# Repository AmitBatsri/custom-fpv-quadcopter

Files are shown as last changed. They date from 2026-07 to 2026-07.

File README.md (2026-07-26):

# Custom FPV Quadcopter
A custom quadcopter built from scratch: STM32F405 flight controller PCB, embedded firmware, ESP-NOW wireless controller, and 3D-printed frame.
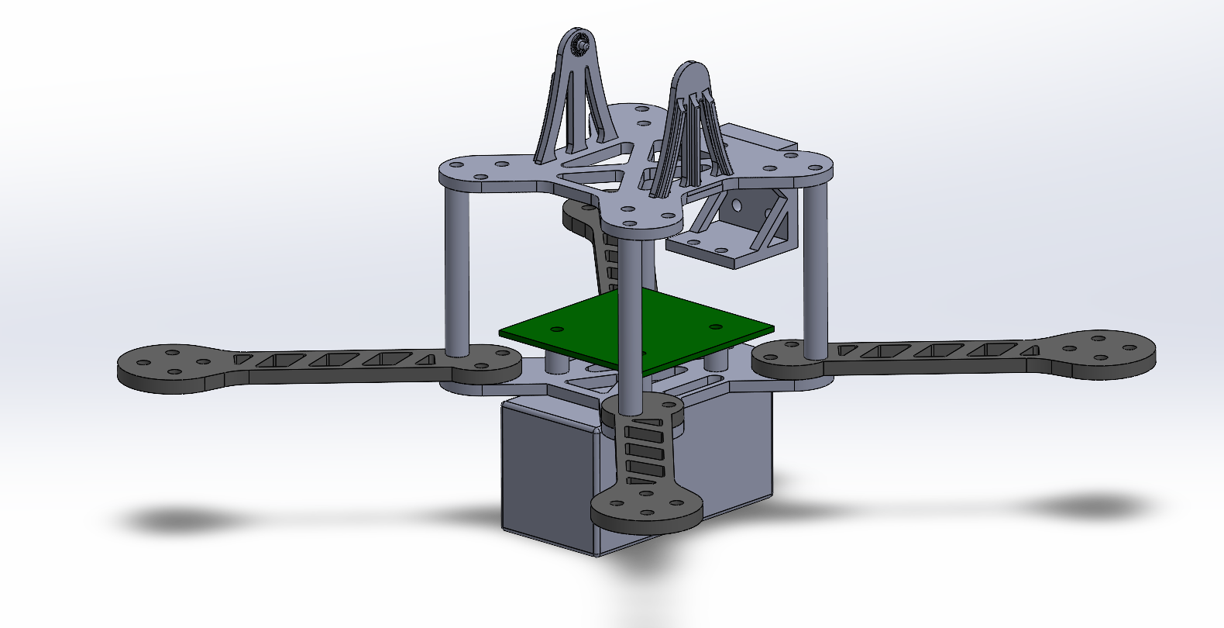
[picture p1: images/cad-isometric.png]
Full CAD assembly

## Overview

This project is a 5-inch FPV quadcopter featuring a fully custom frame, electronics package, and firmware built from individual parts using university equipment and resources. At its core is a custom 4-layer flight controller PCB built around an STM32F405 microcontroller, interfacing with an IMU and barometer over SPI, I²C, and UART. The drone communicates wirelessly through ESP-NOW with a custom handheld controller, and the goal is to achieve stable flight with live video streaming from an onboard camera.

The motivation behind the project is to gain hands-on experience in PCB design, embedded systems, and industry tools including KiCad, SolidWorks, and STM32CubeIDE. In addition, I find flight and aerial technology fascinating as they draw multiple engineering concepts to life. Rather than using an off-the-shelf flight controller, designing the project from the ground up meant working through the full engineering process, integrating mechanical design, embedded systems, and software development.

The part I'm most proud of is the flight controller PCB. Designing it from a blank schematic meant making every engineering decision myself, including component selection, power architecture, sensor integration, and layout with attention to multi-rail power distribution and noise isolation, which are all choices and considerations crucial to the performance of the drone. 

Future goals: autonomous flight capabilities and a potential payload claw mechanism.

## System Architecture

The system is split into three independent subsystems: a handheld 3D-printed controller, the drone's flight and communication electronics, and a standalone video feed. The controller and drone communicate wirelessly over ESP-NOW, while the onboard ESP32-CAM streams video directly to a browser over its own Wi-Fi connection.

```mermaid
graph TD
    subgraph Controller["Handheld Controller"]
        JS["Joysticks + Switches"]
        OLED["OLED Display"]
        S3["ESP32-S3"]
        JS --> S3
        S3 --> OLED
    end

    subgraph Drone["Drone"]
        WROOM["ESP32-WROOM<br/>(Radio Link)"]
        STM["STM32F405<br/>(Flight Controller)"]
        IMU["IMU"]
        BARO["Barometer"]
        CURR["Current Sensor"]
        ESC["4-in-1 ESC"]
        MOTORS["4 Motors"]

        WROOM -->|UART| STM
        IMU -->|SPI| STM
        BARO -->|I2C| STM
        CURR -->|I2C / ADC| STM
        STM -->|DSHOT| ESC
        ESC --> MOTORS
    end

    subgraph Video["Video Feed"]
        CAM["ESP32-CAM"]
        BROWSER["Browser"]
        CAM -->|Wi-Fi| BROWSER
    end

    S3 <-->|ESP-NOW| WROOM
```

## Hardware

### Flight Controller PCB

The flight controller is a custom 4-layer PCB (52 × 52 mm) built around an STM32F405RGT6 microcontroller. It integrates all sensing, power regulation, and motor interfacing needed to fly the quadcopter on a single compact board.

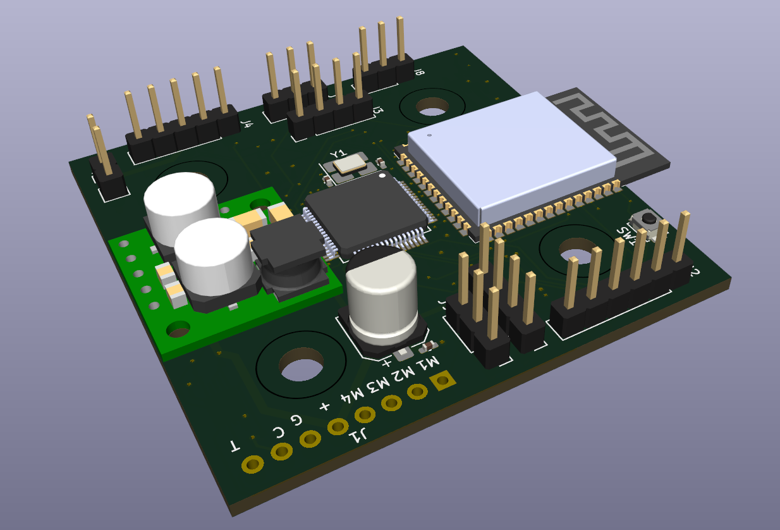
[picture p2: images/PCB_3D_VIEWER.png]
Flight controller 3D view


**Key components:**
- **MCU:** STM32F405RGT6 (168 MHz Cortex-M4F, 1 MB flash)
- **IMU:** BMI270 (SPI) — gyroscope and accelerometer for attitude sensing
- **Barometer:** BMP384 (I2C) — altitude measurement
- **Power monitor:** INA226 (I2C) — battery voltage and current sensing
- **Motor interface:** DSHOT to a 4-in-1 ESC
- **Wireless link:** UART to an onboard ESP32-WROOM

**Power architecture:** The board runs directly off a 4S LiPo, stepping the battery voltage down to a 5 V rail via a buck regulator, then to separate 3.3 V rails through linear voltage regulators consisting of a dedicated rail for the ESP32 to isolate it from the flight-related

**Design highlights:**  Multi-rail power distribution, decoupling placed close to each IC, isolation of sensitive sensor signals from noisy routes, and dense signal routing across layers.

**Design files:**

| Schematic | PCB Layout |
|---|---|
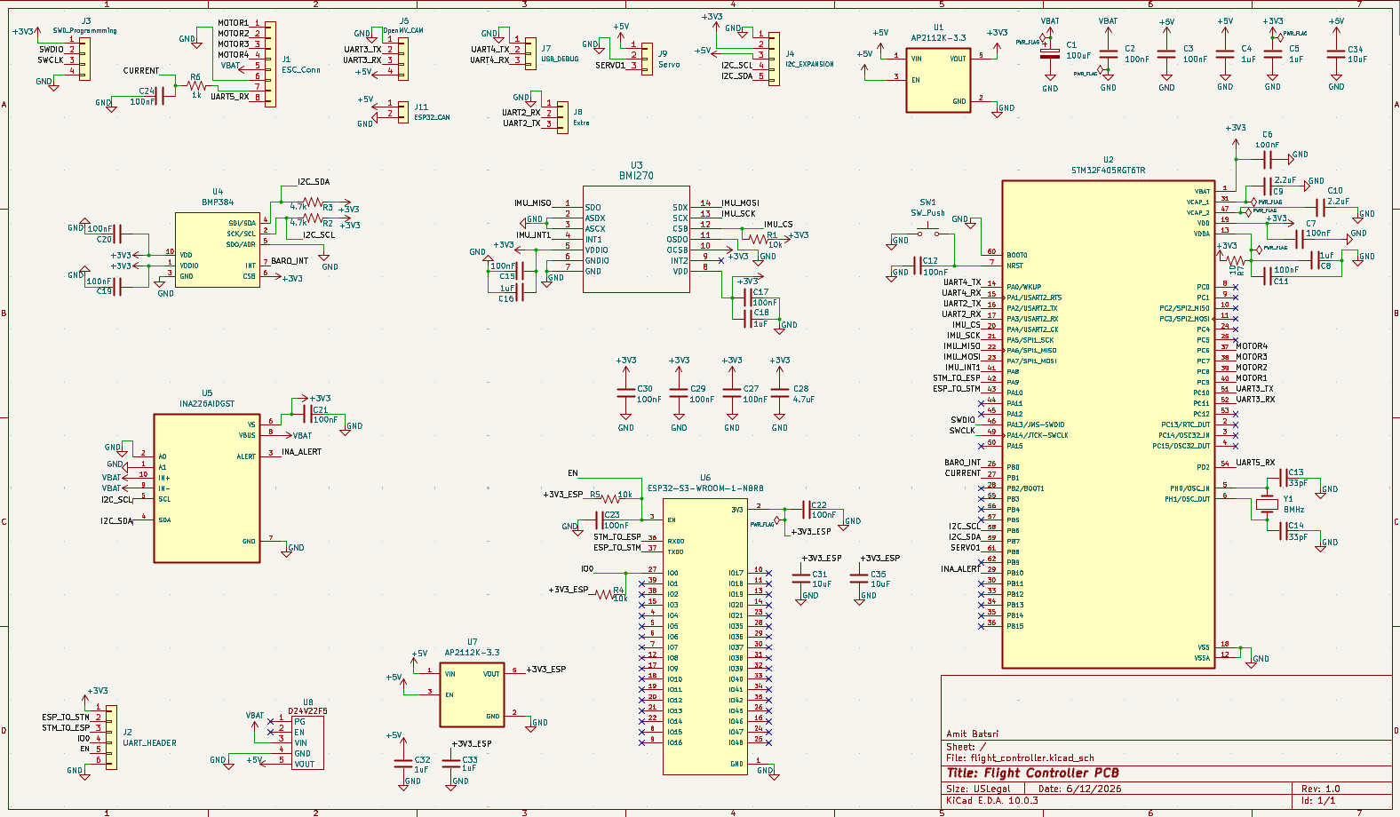
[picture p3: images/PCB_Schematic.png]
Schematic
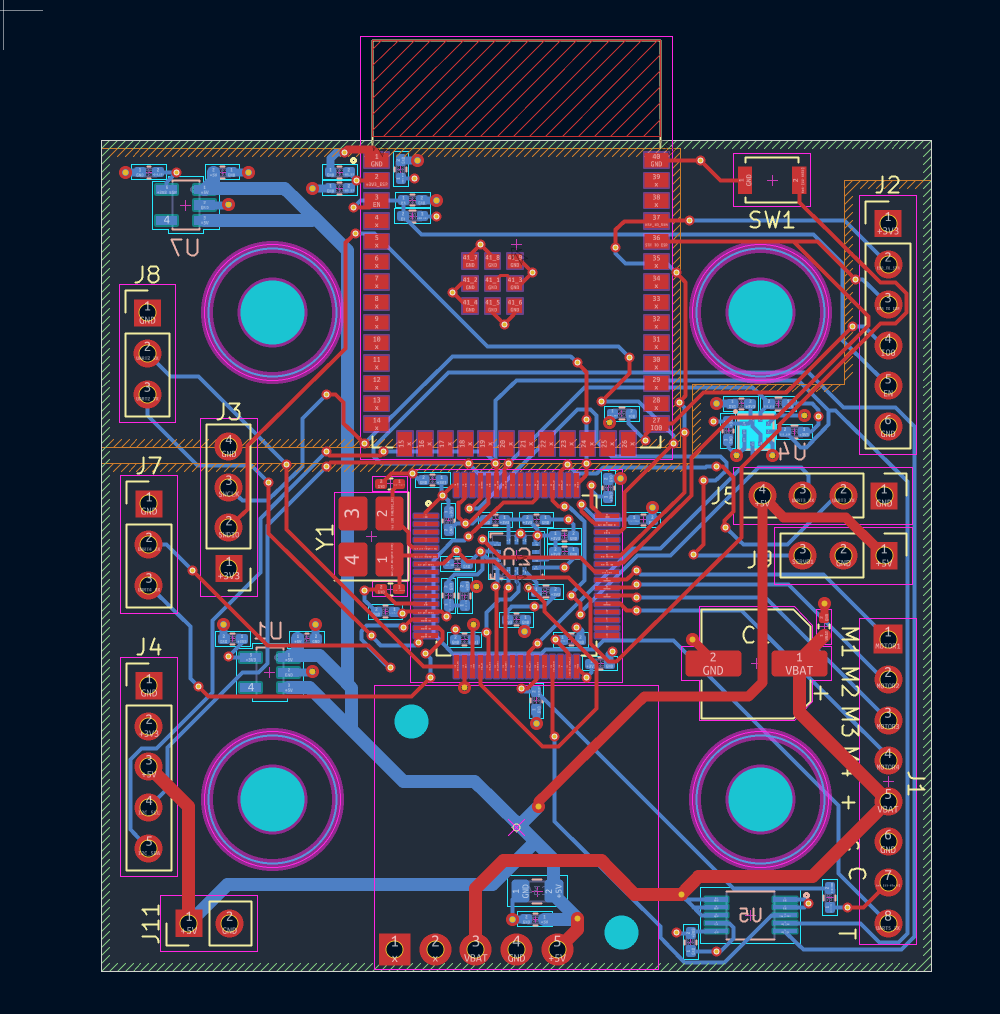
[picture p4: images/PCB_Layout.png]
Layout
|  |  |

**Fabricated board:**

| Top Side | Bottom Side |
|---|---|
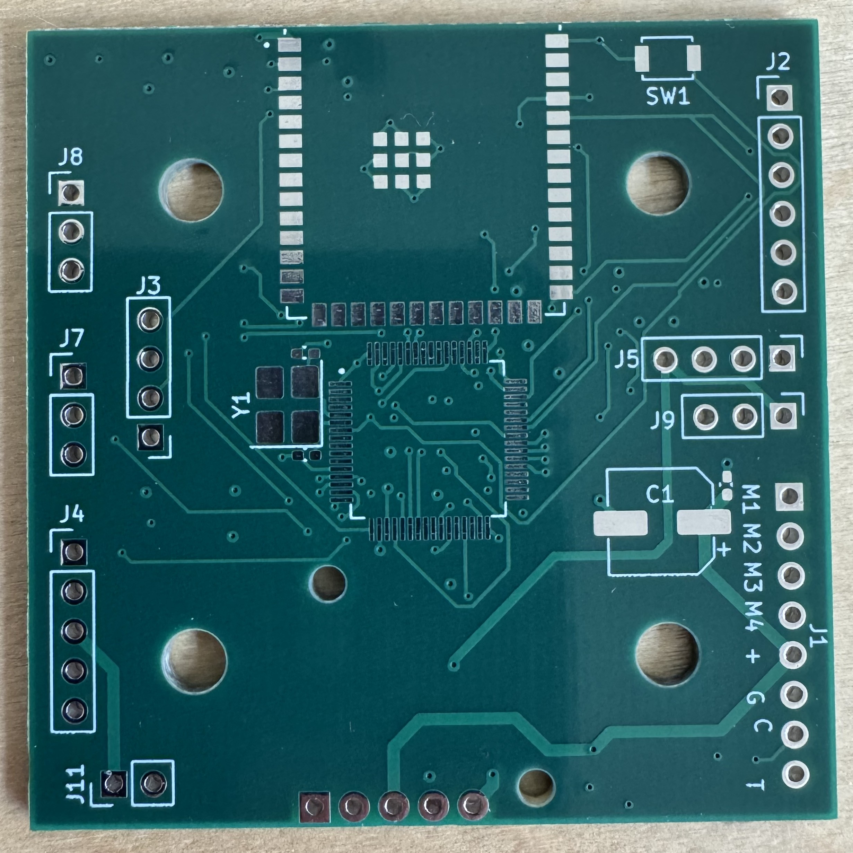
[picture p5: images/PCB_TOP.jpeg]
Top Side
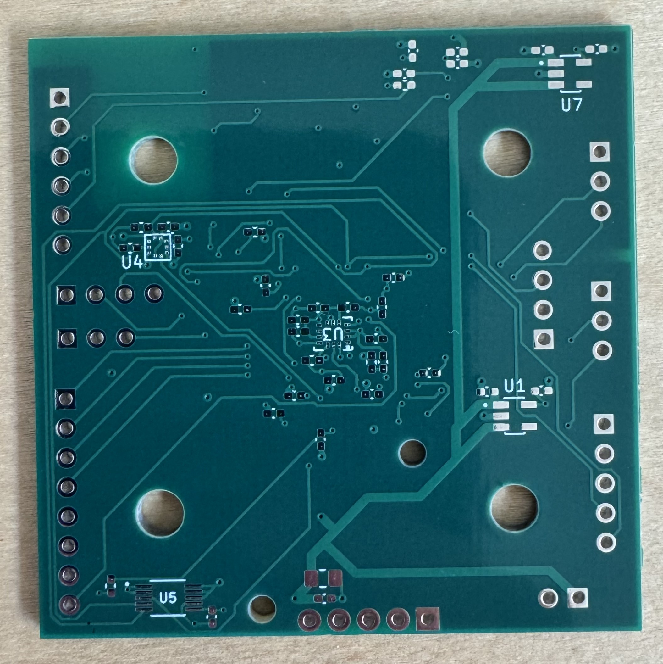
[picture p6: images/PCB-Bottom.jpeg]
Bottom Side
|  |   |

### Handheld Controller PCB

A custom PCB built around an ESP32-S3, featuring two analog joysticks, arming and mode switches, and an OLED display for live status and testing data. The controller sends flight commands and receives telemetry over ESP-NOW.

| Assembled Controller | Controller PCB |
|---|---|
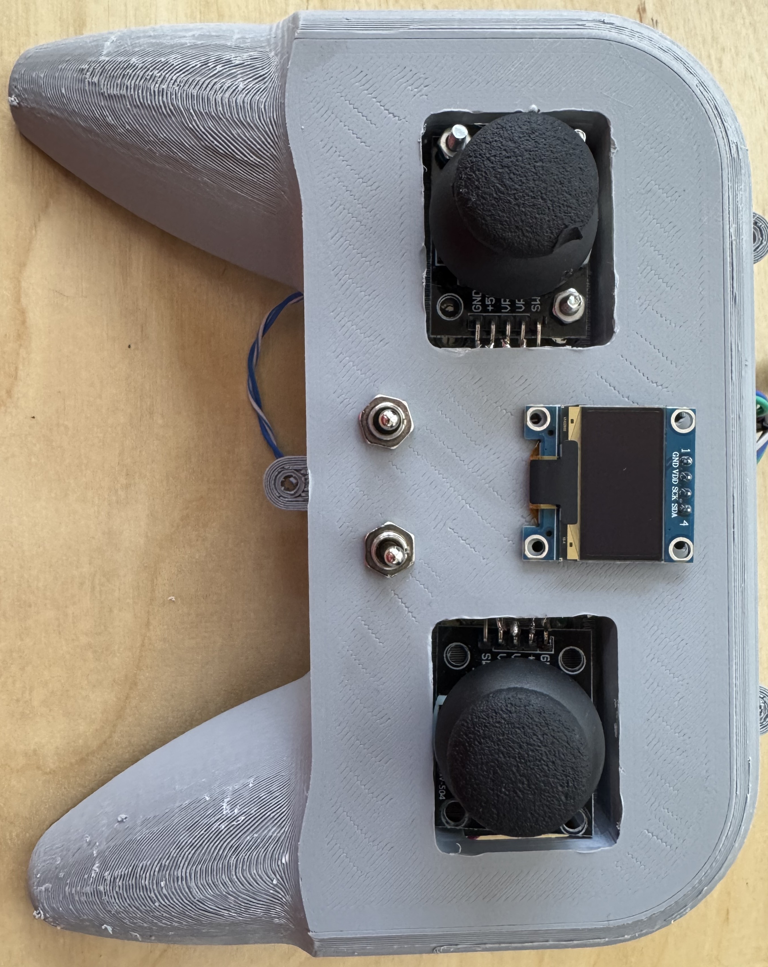
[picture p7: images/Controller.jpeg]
Controller
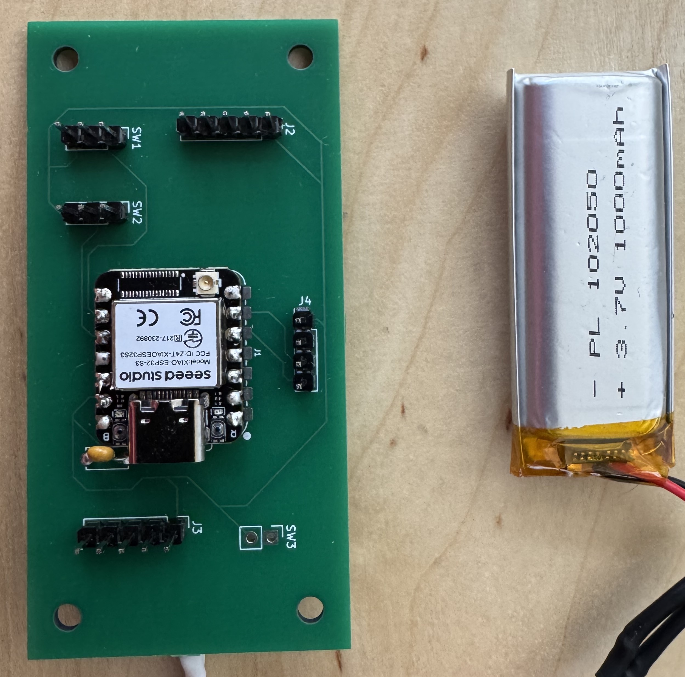
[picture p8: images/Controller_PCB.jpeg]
Controller PCB
|  |  |

## Firmware

The firmware is split across the two microcontrollers: the ESP32-S3 in the controller and the STM32F405 on the drone. All firmware is written in C/C++. The ESP32 code is written in Arduino IDE and the flight controller in STM32CubeIDE using the HAL.

### Wireless Communication (ESP-NOW)

The controller and drone communicate over ESP-NOW, a low-power wireless communication protocol. The link is designed to be robust and safe for flight:

- **Structured packet protocol:** control and telemetry data are sent as fixed, versioned binary packets defined in a shared header, ensuring that both devices always agree on the format.
- **Broadcast-based pairing:** the devices communicate without hardcoded addresses, so the firmware works across different ESP32 modules.
- **Link-quality monitoring:** the controller tracks packet delivery success in real time and calculates the link quality based on the collected data.
- **Fail-safe:** if the drone stops receiving valid control packets, it automatically cuts throttle and disarms in order to prevent flying away and other unwanted behavior

### Controller Firmware (ESP32-S3)

Runs the handheld controller: reads two analog joysticks and arm/mode switches, processes them into throttle, yaw, roll, and pitch values, and updates an OLED display showing live control values and telemetry. Throttle uses an incremental control method that works best with self-centering joysticks, with the arming switch that disables the motors until further command.

### Flight Controller Firmware (STM32F405) — In Progress

The flight controller firmware is currently being developed in STM32CubeIDE. It reads the IMU and barometer, and will implement sensor fusion for attitude estimation, PID stabilization loops, and DSHOT motor control to achieve stable flight. Development is being done incrementally, bringing up and testing each subsystem individually.

## Mechanical Design

Both the drone airframe and the handheld controller enclosure were designed in SolidWorks and 3D-printed.

The drone frame uses a plate-style design sized for 5-inch propellers, consisting of top and bottom plates that house the flight controller stack, four arms, corner spacers, and a mount for the ESP32-CAM.

The controller houses the ESP32-S3 board, joysticks, switches, and OLED display in a custom enclosure designed for a comfortable handheld form factor.

The full CAD models are available in the cad folder.

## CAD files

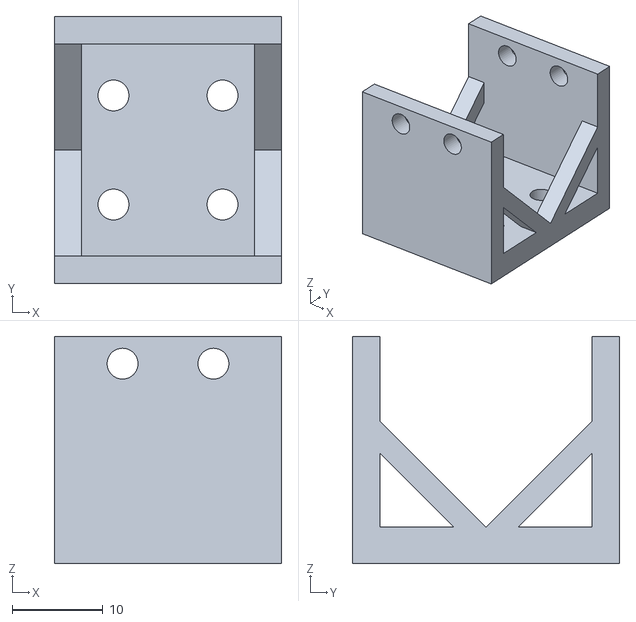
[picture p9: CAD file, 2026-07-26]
cad/Drone_Assembly - Gripper Mount-1.STL
25.0 x 29.4 x 25.0

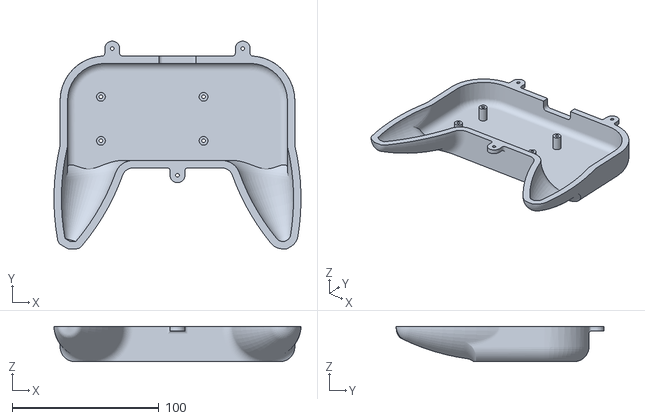
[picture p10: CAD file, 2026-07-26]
cad/Controller_Assembly - Drone_Controller_B-1.STL
168.5 x 141.7 x 24.1

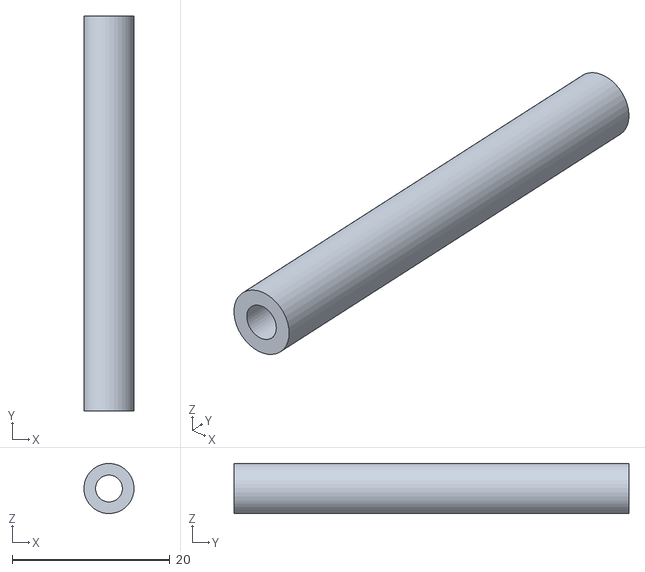
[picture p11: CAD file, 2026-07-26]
cad/Drone_Assembly - Drone_Spacer-1.STL
6.34 x 50.0 x 6.34

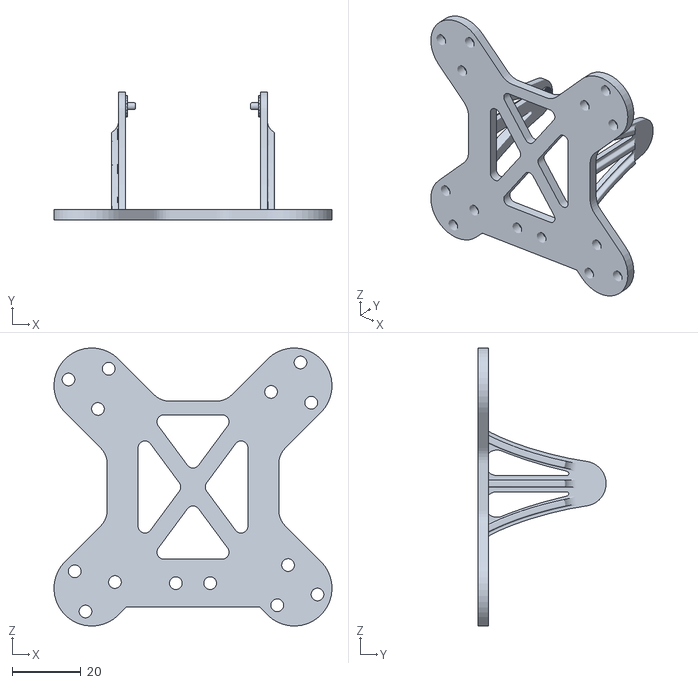
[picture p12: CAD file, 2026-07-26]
cad/Drone_Assembly - Drone_Top_Plate_CAM-1.STL
81.0 x 37.4 x 81.0

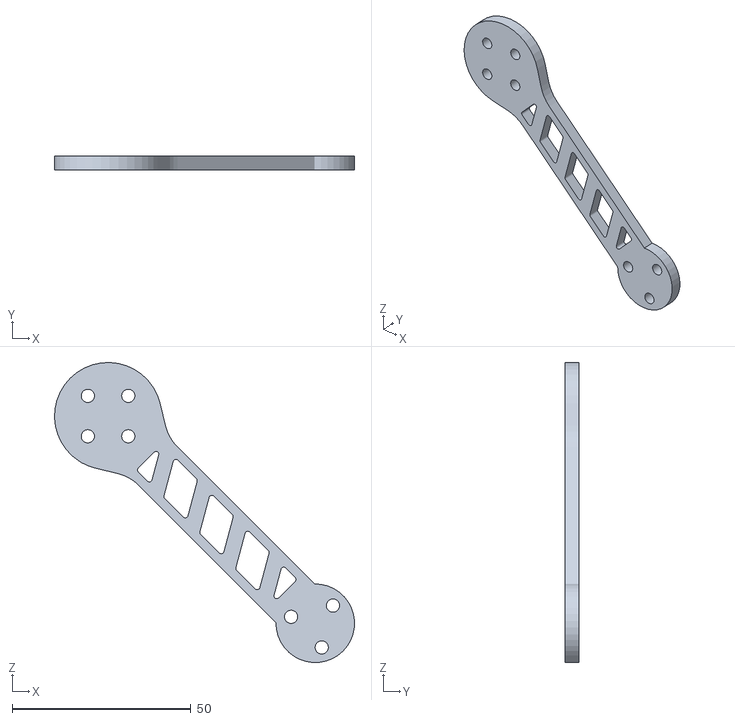
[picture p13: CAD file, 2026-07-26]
cad/Drone_Assembly - Drone_Arm-4.STL
84.0 x 4.00 x 84.0

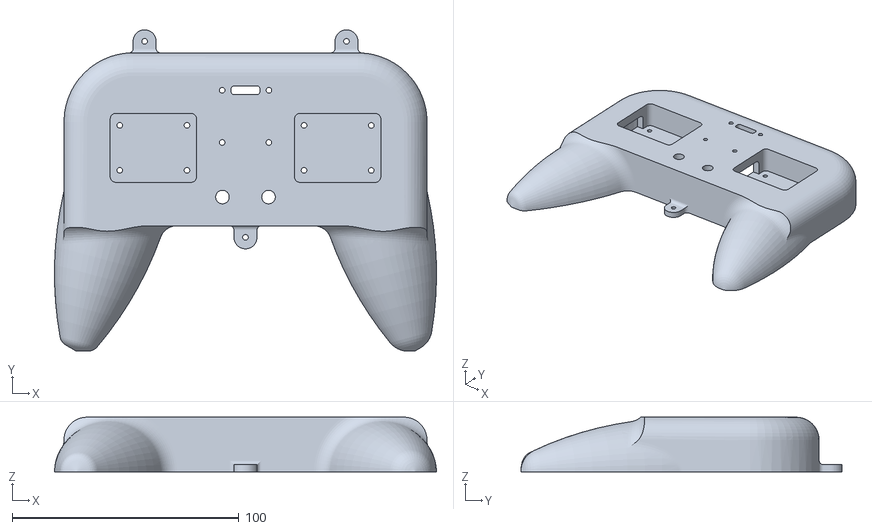
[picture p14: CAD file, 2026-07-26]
cad/Controller_Assembly - Drone_Controller_F-1.STL
168.5 x 141.8 x 24.1

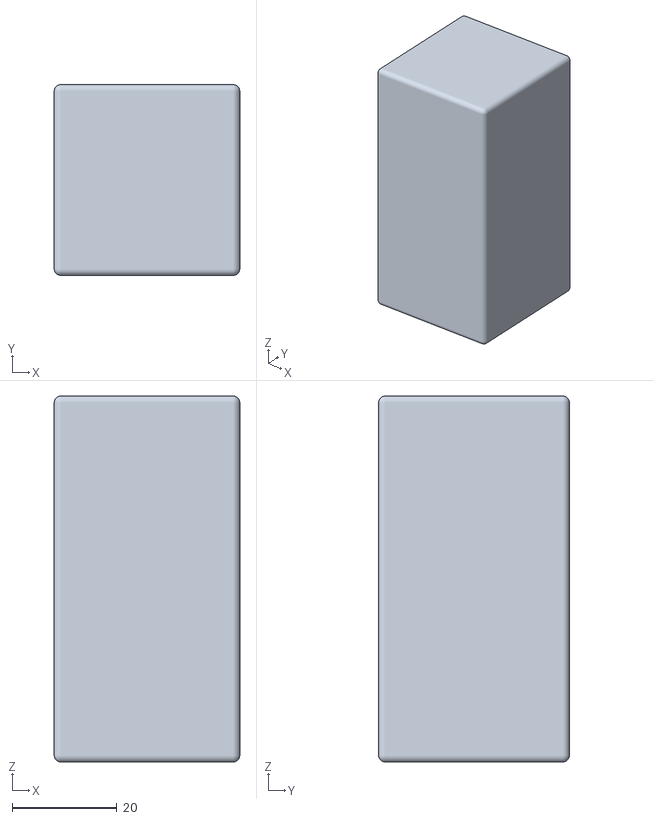
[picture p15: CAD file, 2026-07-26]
cad/Drone_Assembly - Drone_Battery-1.STL
35.5 x 36.5 x 70.0

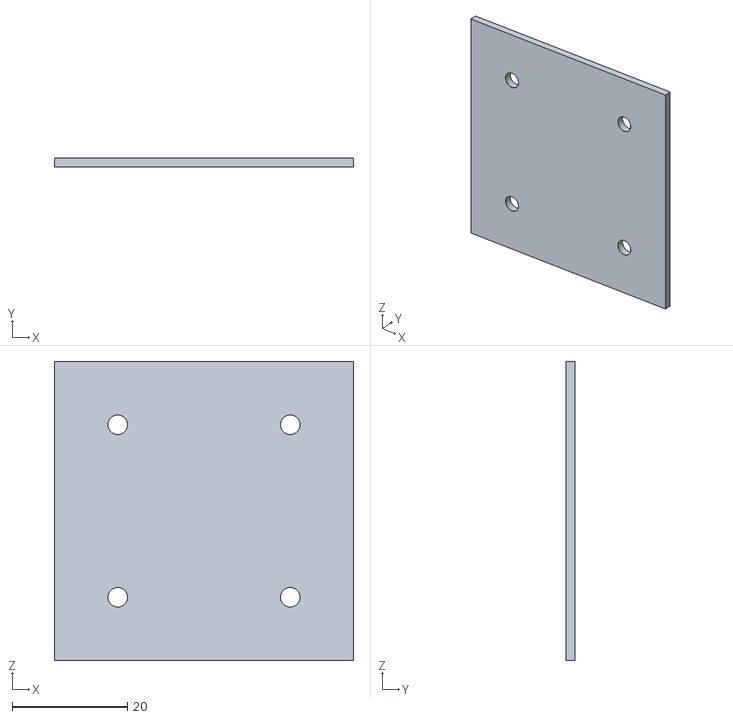
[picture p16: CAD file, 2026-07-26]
cad/Drone_Assembly - Drone_PCB_CAD-2.STL
52.0 x 1.60 x 52.0

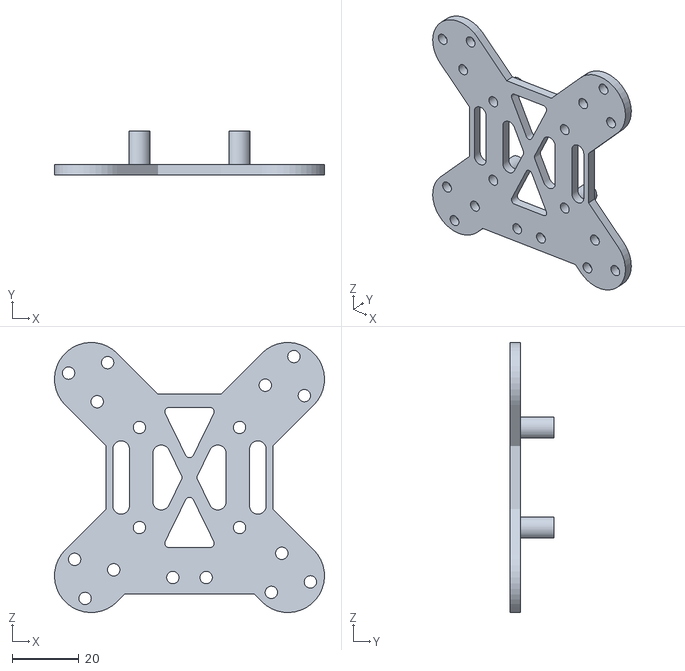
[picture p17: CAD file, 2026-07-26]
cad/Drone_Assembly - Drone_Bottom_Plate-2.STL
81.0 x 13.2 x 81.0

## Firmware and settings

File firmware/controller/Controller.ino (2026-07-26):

#include <Wire.h>
#include <Adafruit_GFX.h>
#include <Adafruit_SSD1306.h>
#include <esp_now.h>
#include <WiFi.h>
#include <esp_wifi.h>         
#include "packets.h"          

struct LeftJoystickOutput {
    float nx;    
    float ny;    
};

struct RightJoystickOutput {
    int roll;    
    int pitch;  
};

#define SCREEN_WIDTH 128
#define SCREEN_HEIGHT 64
#define OLED_RESET -1

const int LEFT_CENTER_X = 1920;
const int LEFT_CENTER_Y = 1897;
const int RIGHT_CENTER_X = 1928;
const int RIGHT_CENTER_Y = 1927;
const float DEADBAND = 0.025;
const int MAX_THROTTLE_INCREMENT = 2;
const int MAX_VAL = 4095;
const int MIN_VAL = 0;

const int DISPLAY_INTERVAL = 200;   
const int SEND_INTERVAL = 20;    //~50 Hz
const int DEBUG_INTERVAL = 200;   

const int JOYSTICK_LX = D2;   
const int JOYSTICK_LY = D3;   
const int JOYSTICK_RX = D1;   
const int JOYSTICK_RY = D0;   
const int ARM_PIN = D8;   
const int MODE_PIN = D9;   

int throttle = 0;
int yaw = 0;
int roll = 0;
int pitch = 0;
bool armed = false;
bool stabilized = true;

unsigned long last_display_update = 0;
unsigned long last_send_time = 0;
unsigned long last_debug_time = 0;

float altitude = 0.0;
float battery = 0.0;
int link_quality = 0;
bool link_lost = false;    

bool display_ok = false;
bool espnow_ok  = false;

Adafruit_SSD1306 display(SCREEN_WIDTH, SCREEN_HEIGHT, &Wire, OLED_RESET);

void setup() {
    Serial.begin(115200);

    pinMode(ARM_PIN, INPUT_PULLUP);
    pinMode(MODE_PIN, INPUT_PULLUP);

    display_ok = display_init();
    espnow_ok = espnow_init();

    if (!display_ok) Serial.println("WARN: display init failed - continuing without display");
    if (!espnow_ok) Serial.println("ERROR: ESP-NOW init failed - no link to drone");
}

void loop() {
    unsigned long now = millis();

    int raw_lx = analogRead(JOYSTICK_LX);
    int raw_ly = analogRead(JOYSTICK_LY);
    int raw_rx = analogRead(JOYSTICK_RX);
    int raw_ry = analogRead(JOYSTICK_RY);

    LeftJoystickOutput out = JoystickOut(raw_lx, raw_ly);
    RightJoystickOutput rout = RightJoystickOut(raw_rx, raw_ry);

    armed = (digitalRead(ARM_PIN) == LOW);
    stabilized = (digitalRead(MODE_PIN) == HIGH);


    if (armed) {
        throttle = throttle_set(out.ny, throttle);
    } else {
        throttle = 0;
    }
    yaw = yaw_set(out.nx);
    roll = rout.roll;
    pitch = rout.pitch;

    if (espnow_ok && (now - last_send_time >= SEND_INTERVAL)) {
        last_send_time = now;
        send_control_packet();
    }

    if (display_ok && (now - last_display_update >= DISPLAY_INTERVAL)) {
        last_display_update = now;
        if (armed)
            display_flight_mode();
        else
            display_test_mode();
    }
    if (now - last_debug_time >= DEBUG_INTERVAL) {
        last_debug_time = now;
        Serial.print("THR: ");  Serial.print(throttle);
        Serial.print(" YAW: "); Serial.print(yaw);
        Serial.print(" ROL: "); Serial.print(roll);
        Serial.print(" PIT: "); Serial.print(pitch);
        Serial.print(" ARM: "); Serial.print(armed);
        Serial.print(" MOD: "); Serial.println(stabilized);
    }
}

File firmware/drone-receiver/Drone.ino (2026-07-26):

#include <esp_now.h>
#include <WiFi.h>
#include <esp_wifi.h>        
#include "packets.h"    

volatile ControlPacket latest;          
volatile bool have_packet = false;  
volatile uint32_t last_packet_time = 0; 

bool failsafe_active = false;

int  throttle = 0;
int  yaw = 0, roll = 0, pitch = 0;
bool armed = false, stabilized = true;

uint8_t last_seq = 0;
bool     seq_valid = false;
uint32_t dropped_count = 0;

static const uint32_t TELEM_SEND_INTERVAL = 100;   
uint32_t last_telem_send = 0;

static const uint32_t DBG_INTERVAL = 200;       
uint32_t last_dbg = 0;

void on_data_received(const uint8_t *mac, const uint8_t *data, int len) {
    if (len < (int)sizeof(ControlPacket)) return;  

    ControlPacket pkt;
    memcpy(&pkt, data, sizeof(pkt));

    if (pkt.version != PROTOCOL_VERSION) return;     
    if (pkt.type != MSG_CONTROL) return;     

    if (seq_valid) {
        uint8_t expected = (uint8_t)(last_seq + 1);
        if (pkt.seq != expected) {
            dropped_count += (uint8_t)(pkt.seq - expected);
        }
    }
    last_seq = pkt.seq;
    seq_valid = true;

    latest = pkt;
    have_packet = true;
    last_packet_time = millis();
}

void on_data_sent(const uint8_t *mac, esp_now_send_status_t status) {
}

void apply_failsafe() {
    uint32_t now = millis();

    bool stale = (!have_packet) || (now - last_packet_time > LINK_TIMEOUT_MS);

    if (stale) {
        failsafe_active = true;
        throttle = 0; 
        yaw = roll = pitch = 0;
        armed = false;    
    } else {
        failsafe_active = false;
        throttle = latest.throttle;
        yaw = latest.yaw;
        roll = latest.roll;
        pitch = latest.pitch;
        armed = (latest.flags & FLAG_ARMED) != 0;
        stabilized = (latest.flags & FLAG_STABILIZED) != 0;
        if (!armed) throttle = 0;
    }
}

void send_telemetry() {
    TelemetryPacket t;
    t.version = PROTOCOL_VERSION;
    t.type = MSG_TELEMETRY;
    t.altitude_cm = 150;      
    t.battery_mv = 14200;      
    t.link_quality = failsafe_active ? 0 : 100;  
    t.flags = 0;
    
    esp_now_send(BROADCAST_ADDR, (uint8_t*)&t, sizeof(t));
}

void setup() {
    Serial.begin(115200);

    WiFi.mode(WIFI_STA);
    WiFi.disconnect();
    esp_wifi_set_channel(ESPNOW_CHANNEL, WIFI_SECOND_CHAN_NONE);  

    if (esp_now_init() != ESP_OK) {
        Serial.println("ESP-NOW init failed");
        return;
    }

    esp_now_register_recv_cb(on_data_received);
    esp_now_register_send_cb(on_data_sent);

    esp_now_peer_info_t peer;
    memset(&peer, 0, sizeof(peer));
    memcpy(peer.peer_addr, BROADCAST_ADDR, 6);
    peer.channel = ESPNOW_CHANNEL;
    peer.encrypt = false;

    if (esp_now_add_peer(&peer) != ESP_OK) {
        Serial.println("Failed to add broadcast peer");
        return;
    }

    Serial.println("Drone receiver ready (broadcast)");
}

void loop() {
    uint32_t now = millis();
    apply_failsafe();

    if (now - last_telem_send >= TELEM_SEND_INTERVAL) {
        last_telem_send = now;
        send_telemetry();
    }

    if (now - last_dbg >= DBG_INTERVAL) {
        last_dbg = now;
        if (failsafe_active) {
            Serial.print("[FAILSAFE] link lost - throttle forced 0   dropped=");
            Serial.println(dropped_count);
        } else {
            Serial.print("THR: ");  Serial.print(throttle);
            Serial.print(" YAW: "); Serial.print(yaw);
            Serial.print(" ROL: "); Serial.print(roll);
            Serial.print(" PIT: "); Serial.print(pitch);
            Serial.print(" ARM: "); Serial.print(armed);
            Serial.print(" MOD: "); Serial.print(stabilized);
            Serial.print(" DROP: "); Serial.println(dropped_count);
        }
    }
}

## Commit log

2026-07-25 Fix image links in README for flight controller PCB
    Updated image links in the README to include file extensions for proper rendering.
2026-07-26 Rename Contrtoller_Assembly - Drone_Controller_F-1.STL to Controller_Assembly - Drone_Controller_F-1.STL
    [Controller_Assembly - Drone_Controller_F-1.STL]
2026-07-26 Rename Contrtoller_Assembly - Drone_Controller_B-1.STL to Controller_Assembly - Drone_Controller_B-1.STL
    [Controller_Assembly - Drone_Controller_B-1.STL]
2026-07-26 Update README with mechanical design information
    Added details about mechanical design and CAD models.
